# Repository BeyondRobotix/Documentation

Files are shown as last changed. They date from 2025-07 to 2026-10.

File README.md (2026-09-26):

# Beyond Robotix Documentation

Documentation for [Beyond Robotix](https://www.beyondrobotix.com/) hardware and firmware.

## Heated Pitot

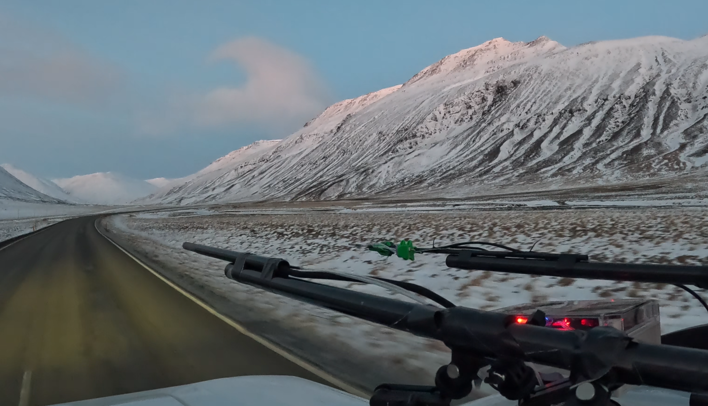
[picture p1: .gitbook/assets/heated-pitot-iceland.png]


Keeps aircraft airspeed readings accurate through extreme icing and wet conditions, with DroneCAN control and precise heater power management.

* [Heated Pitot](heated-pitot/)

## Kahuna

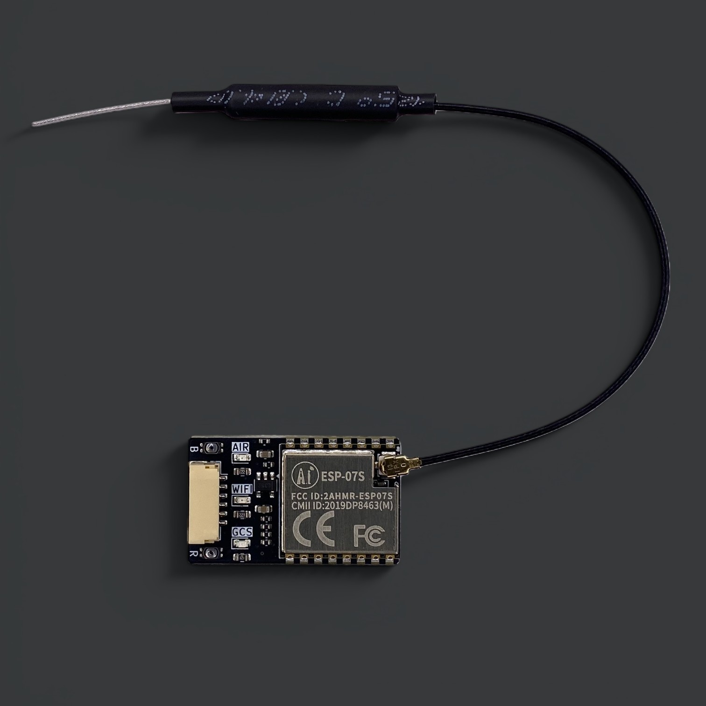
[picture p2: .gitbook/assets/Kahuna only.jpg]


A Wi-Fi telemetry unit for the Pixhawk ecosystem. Connect from any laptop or tablet with Mission Planner or QGroundControl, with multi-drone support and long range up to 2.5km.

* [Kahuna](kahuna/)
* [Quick Start Guide](kahuna/quick-start-guide.md)

## CAN Ecosystem

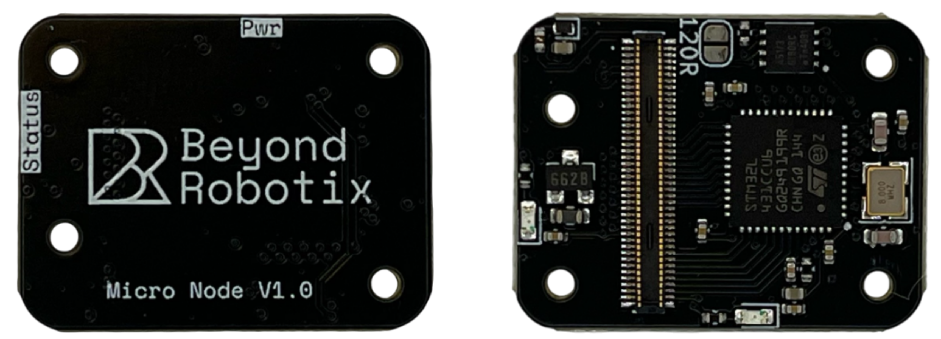
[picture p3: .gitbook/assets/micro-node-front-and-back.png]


Hardware and firmware for building custom DroneCAN peripherals, from ready-made nodes to Arduino-based custom firmware.

* [CAN Ecosystem overview](can-ecosystem/)
* [Micro Node](can-ecosystem/micro-node.md) — a compact CAN node that mounts to a custom carrier board
* [Node Development Board V1.1](can-ecosystem/node-development-board-v1.1.md) — breaks out every Micro Node interface for development
* [CAN Node](can-ecosystem/l431-can-node.md) — the same STM32L431 as the Micro Node, in a standalone form factor
* [CAN Node Plus](can-ecosystem/can-node-plus.md) — dual CAN FD interfaces and an STM32H723 for more demanding applications
* [Arduino DroneCAN](can-ecosystem/arduino-dronecan/) — build custom firmware for any of our nodes with a familiar Arduino sketch
* [AP Periph](can-ecosystem/ap-periph.md) — the ready-made ArduPilot peripheral firmware our nodes ship with by default

## Air Data Module

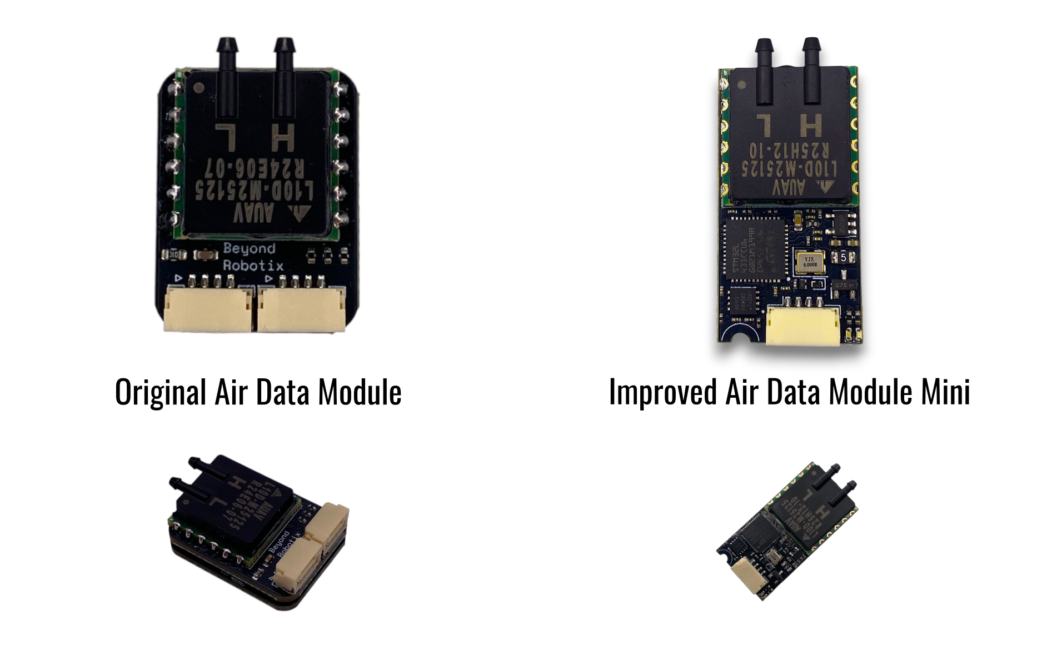
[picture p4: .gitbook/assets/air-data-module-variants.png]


A DroneCAN airspeed and altitude sensor built around the AllSensors AUAV pressure sensor, supporting a range of autopilots.

* [Air Data Module](air-data-module/)
* [Quick Start Guide](air-data-module/quick-start-guide.md)
* [Air Data Module Mini](air-data-module/air-data-module-mini.md) — a more compact, reliable redesign of the original module
* [Air Data Module Original](air-data-module/air-data-moulde-original.md) — the original two-layer design, mounted on a Micro Node

## RM3100 DroneCAN Compass

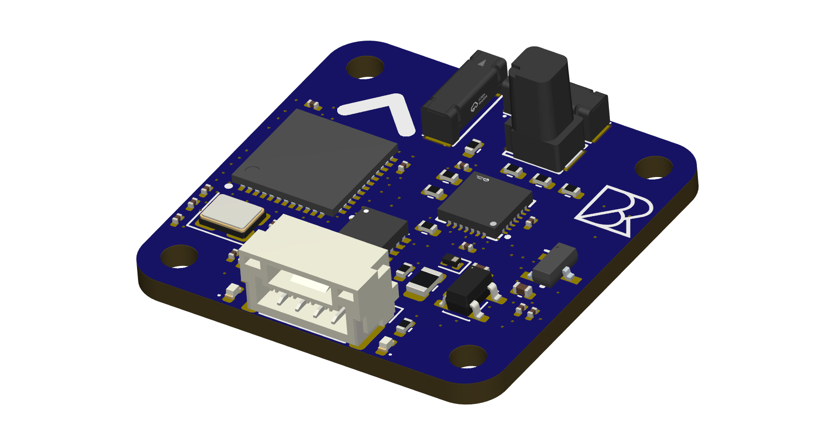
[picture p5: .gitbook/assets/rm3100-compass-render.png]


A plug-and-play DroneCAN magnetometer node built around the PNI RM3100 sensor, with the standard Pixhawk JST-GH connector.

* [RM3100 DroneCAN Compass](rm3100-dronecan-compass.md)

## Core Autopilot

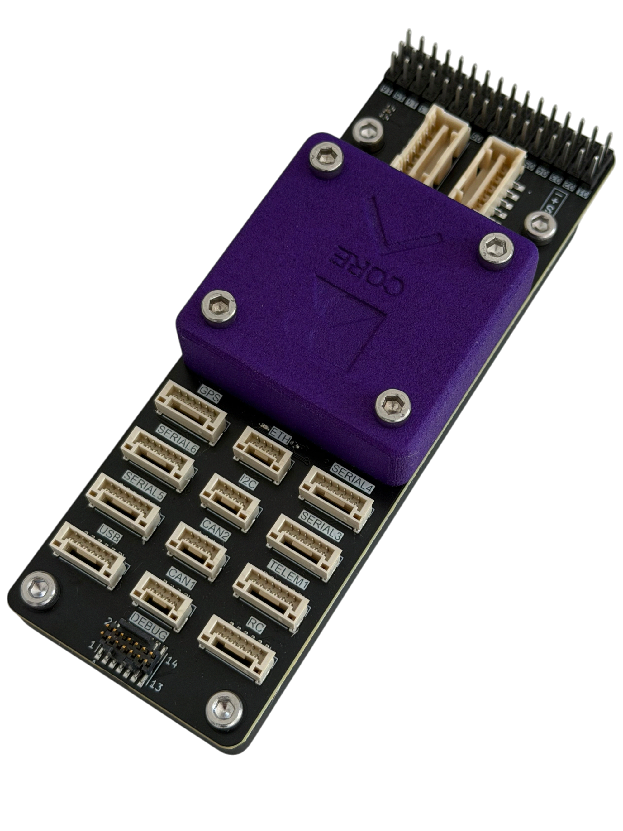
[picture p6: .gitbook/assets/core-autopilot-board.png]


An ArduPilot and PX4 compatible autopilot with 16 PWMs, Ethernet, 7 serials, 2 CAN and I2C, built around a modular Core plus carrier board design.

* [Core Autopilot](core-autopilot/)
* [Core Pinout](core-autopilot/core-pinout.md) — integrate the Core into your own carrier board
* [Default Carrier](core-autopilot/default-carrier-pinout.md) — pinout and mechanical for our reference carrier
* [Core Power](core-autopilot/core-power.md)

## Reference

* [Engineering Change Notice](engineering-change-notice.md) — hardware changes to our products (see GitHub releases for software changes)

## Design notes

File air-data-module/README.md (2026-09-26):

---
description: DroneCAN enabled AUAV absolute and differential pressure sensor
---

# Air Data Module

## Introduction

The Beyond Robotix Air Data Modules makes use of the Allsensors AUAV sensor. This module has a differential and absolute pressure sensors to estimate airspeed and altitude. The module works over DroneCAN with a variety of autopilots.

<figure><figcaption></figcaption></figure>

There are 5 variants of the air data module, each with their own maximum speeds:

* L05D → 45m/s&#x20;
* L10D → 63m/s
* L30D → 111m/s
* L60D → 149m/s
* L100D → 193m/s

For the best performance, choose the variant with the lowest speed that your platform will not exceed the maximum speed of. For example, if your platforms maximum speed is 50m/s, choose the L10D with the upper limit of 63 m/s. The L05D is not suitable as you will saturate the sensor. Going marginally over the maximum speed of the sensor will not damage it. The proof pressure (the point where the sensor will exhibit permenant damage) is 67 kPa, which equates to about 330 m/s - approximately Mach 0.97!

### Buy Now

{% embed url="https://www.beyondrobotix.com/products/air-data-module" %}

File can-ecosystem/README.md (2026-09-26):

# CAN Node System

The micro CAN node system allows easy integration of a CAN node into your project! We've solved the CAN node hardware and software problems, so you can create your custom solution rapidly.

If you're interested in a custom carrier board, or have any engineering enquiries please contact us at admin@beyondrobotics.com. We can also write custom firmwares for you!

## Getting Started

If you've just received your CAN node product, we have all the hardware and software details here!

If you can't find something in the docs or have more questions, contact us at **admin@beyondrobotix.com**

### Micro Node

The Micro Node carriers the STM32L431 chip with all required hardware. It has a high density connector to interface with the Node Develpment board, or any other board that fits a Micro Node.

{% embed url="https://www.beyondrobotix.com/products/micro-can-node" %}

<figure><figcaption><p>Micro Node </p></figcaption></figure>

### Node Development Board

The Node Development Board breaks out all the interfaces from the mounted node, including UART, SPI, I2C, USB, STLINK, CAN, Analogue and GPIOs.

{% embed url="https://www.beyondrobotix.com/products/micro-can-node-development-bundle" %}

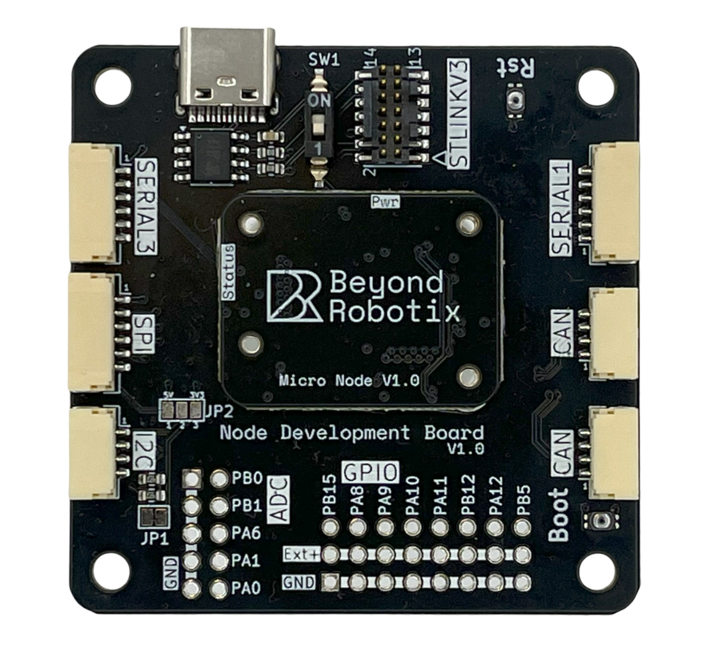
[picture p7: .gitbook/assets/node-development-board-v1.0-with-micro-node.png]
<figure><figcaption><p>Carrier board with Micro Node Mounted</p></figcaption></figure>

### CAN Node

The same STM32L431 as the Micro Node, but as a standalone board rather than one that mounts to a carrier. Interfaces come out on JST-GH connectors and a 2.54mm header, and it has the same debug port for developing Arduino DroneCAN applications. Pick this one when you don't need a custom carrier board.

{% embed url="https://www.beyondrobotix.com/products/can-node" %}

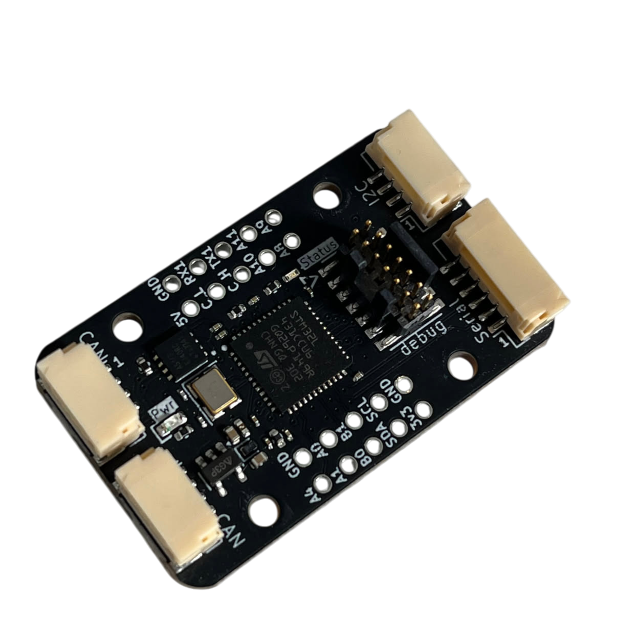
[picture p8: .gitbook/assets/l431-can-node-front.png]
<figure><figcaption><p>CAN Node</p></figcaption></figure>

{% content-ref url="l431-can-node.md" %}
[l431-can-node.md](l431-can-node.md)
{% endcontent-ref %}

### CAN Node Plus

Our H7 node. Two fully independent CAN FD interfaces, a lot more processing power than the L431 nodes, and JST-GH connectors for serial, I2C, SPI and PWM following the same conventions as an autopilot.

{% embed url="https://www.beyondrobotix.com/products/can-node-plus" %}

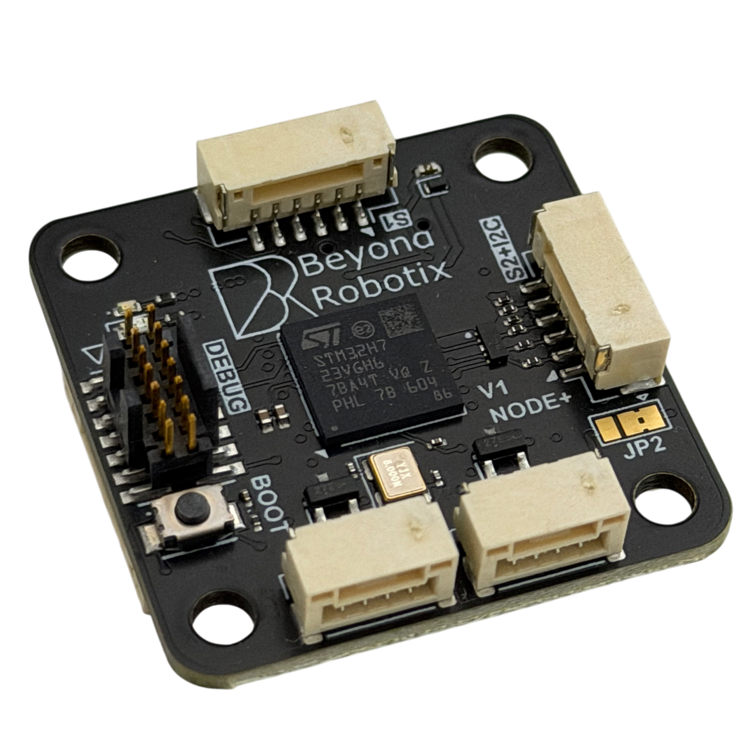
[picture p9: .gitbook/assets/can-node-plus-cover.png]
<figure><figcaption><p>CAN Node Plus</p></figcaption></figure>

{% content-ref url="can-node-plus.md" %}
[can-node-plus.md](can-node-plus.md)
{% endcontent-ref %}

### Arduino DroneCAN

You can integrate your sensor how you like with minimal code and using pre-existing Arduino libraries. Includes bootloader support so your apps can be updated over CAN.

Perfect for your custom hardware solutions, or if you want to implement your own logic!

{% content-ref url="arduino-dronecan/" %}
[arduino-dronecan](arduino-dronecan/)
{% endcontent-ref %}

### AP Periph

Ardupilots swiss army knife, no code required with many common sensors supported [https://ardupilot.org/dev/docs/ap-peripheral-landing-page.html](https://ardupilot.org/dev/docs/ap-peripheral-landing-page.html)

Details on our specific AP periph firmware are on the following page:

{% content-ref url="ap-periph.md" %}
[ap-periph.md](ap-periph.md)
{% endcontent-ref %}

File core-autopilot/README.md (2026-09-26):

# Core Autopilot

{% hint style="info" %}
This page is under construction. Please contact admin@beyondrobotix.com for further information.
{% endhint %}

<figure style="text-align: center"><figcaption><p>Beyond Robotix Core Autopilot </p></figcaption></figure>

The Beyond Robotix Core is an Ardupilot and PX4 compatible autopilot, aimed to increase the flexibility and number of interfaces over other solutions whilst being simple to integrate into any drone. 16 PWMs, Ethernet, 7 serials, 2 CAN and I2C all contribute to ensure you can achieve what you need to.

The Core integrates all power conditioning and switching within the core, so a carrier board only needs to route from the high density connectors to the carrier outputs.

## Sensors

The core contains tripple redundant IMUs, dual barometers and a single Magnetometer. All sensors are heated using a 2W heater to ensure they operate consistently in any scenario. The 2W heater is able to bring the sensors to working temperature within minutes even at extreme cold temperatures. 

| Sensor | Part |
| --- | --- |
| IMU | 2× IIM-42652, 1× BMI088 |
| Barometer | 2× MS5611 |
| Magnetometer | 1× BMM350 |

## Power

The Core accepts power through 4 interfaces
- USB C
- USB JST-GH header
- Power 1
- Power 2

The following applies to the inputs:
- All inputs and all outgoing 5 V rails are clamped at 5.5 V against transients
- Every input is filtered and reverse-blocked
- The highest voltage input is used, or, similar voltage sources are shared.
- The power inputs expect a 4.8V-5.75V input, with a recommended input of 5.3V.

### Power outputs
The core has 3 power lanes. One directly for the processor which is the priority, then 2 avionics lanes, Telem and peripherals. 

<figure><figcaption><p>5V bus distribution on the power layer</p></figcaption></figure>

### Redundancy behaviour

Each input is independently protected and reverse-blocked. A source that fails, is disconnected, or drops outside the accepted voltage window is isolated automatically, without disturbing the others and without back-feeding the board or another source. Changeover requires no configuration, and the board continues on whatever remains.

## Connectivity

- 2x CAN interfaces
- Ethernet
- USB
- microSD
- SWD/JTAG debug
- 7 Serial
- I2C

{% hint style="info" %}
USB signals are common between the USB-C connector on the side of the core and the USB connector on the connector layer.
{% endhint %}

- All digital signal lines have ESD protection 
- Analogue inputs are series-protected and filtered

## Mechanical

The core and its carrier boards are designed to be removable from an aircraft after being mounted, all screws are top accessible which allows maintenance once the aircraft has been built. The core and carriers use M3 screws to keep tooling consistent.

Carrier board mechanical (outline, mounting holes, STEP file) is covered on the [Default Carrier](default-carrier-pinout.md#mechanical) page.

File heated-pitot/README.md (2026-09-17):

# Heated Pitot

{% hint style="info" %}
This page is under construction. Please contact admin@beyondrobotix.com for further information.
{% endhint %}

The Beyond Robotix Heated Pitot allows aircraft to continue reading airspeed during extreme icing and wet conditions. It's able to operate at high airspeeds, with significant heating power on demand if required. The probe integrates our AUAV airspeed sensor module, for altitude and airspeed estimates over wide speed range options. DroneCAN is used for readings and optional control, with support for both Ardupilot and PX4. Our electronics allow precise power control, meaning your avionics system is not put under stress even when high heating power is required.

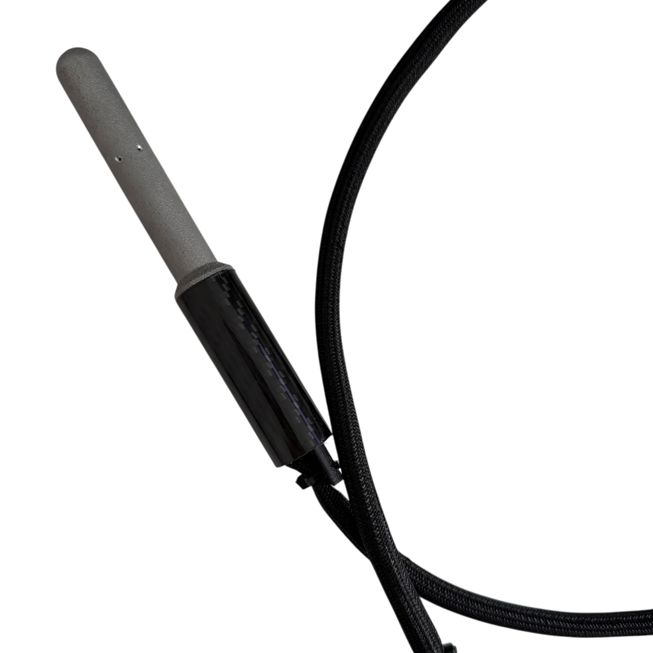
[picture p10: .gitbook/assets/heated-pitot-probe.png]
<div><figure><figcaption></figcaption></figure> <figure><figcaption></figcaption></figure></div>

For large volume orders, we can support custom options:
- loom length between control module and pitot
- Tube length to the probe
- Custom mounts

## Mechanical

### Probe 

{% file src="../.gitbook/assets/Beyond Robotix Heated Pitot Space Model.step" %}

### Control module

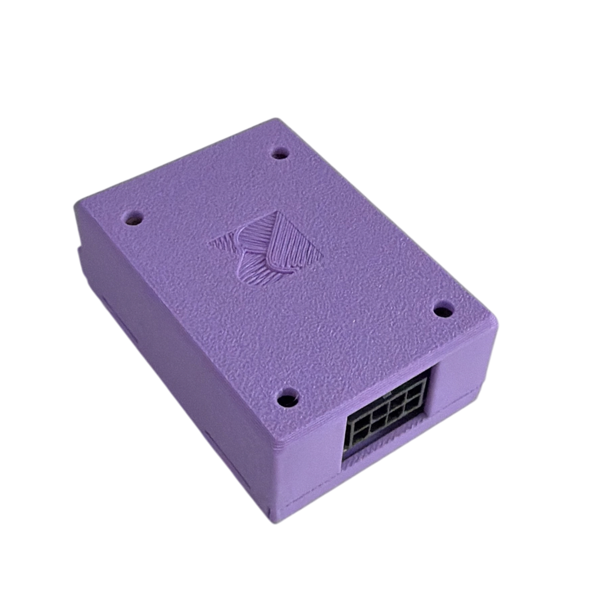
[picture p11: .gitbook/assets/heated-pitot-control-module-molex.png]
<figure><figcaption></figcaption></figure>

{% file src="../.gitbook/assets/Heated Pitot Control Module.step" %}

## Electrical

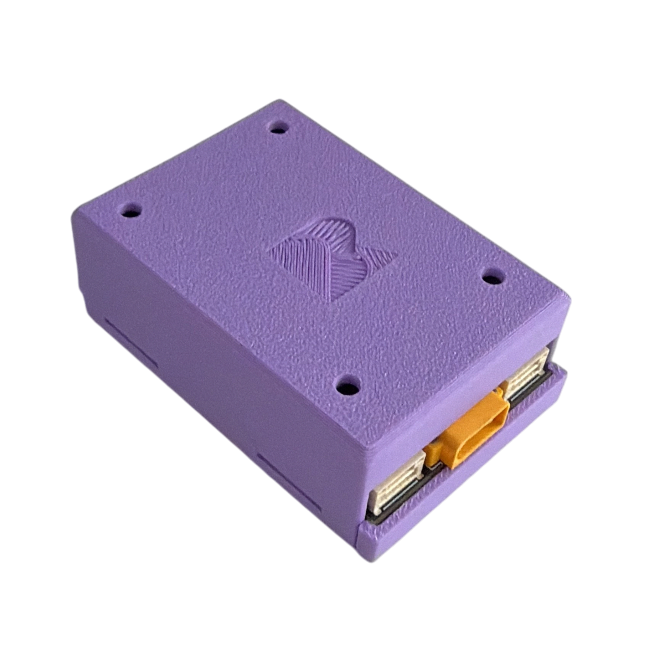
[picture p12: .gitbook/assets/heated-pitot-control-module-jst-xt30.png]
<figure><figcaption></figcaption></figure>

{% hint style="warning" %}
Below 12V, the maximum available heater power output will reduce. The pitot may operate down to 9V. Below 12V operation is not recommended.
{% endhint %}

| Parameter | Value |
| --- | --- |
| Input Voltage Range | 12 - 53 V |
| Maximum Power Consumption | 70 W (settable, see `P_MAX`) |
| Standby Power | 1 W |
| Operating Temperature Range | -40 °C to +80 °C |
| Power Connector | XT30 |
| 5V / CAN Connector | 2x standard 4 pin JST-GH |

### Power Consumption

The pitot targets a set temperature and adjusts heater power output to meet temperature demand. We recommend a 60 degree target temperature to ensure ice is melted as quickly as possible. For this given target temperature, the power output varies depending on airspeed, atmospheric temperature, altitude, snow/water air content.

The following shows power consumption varying with airspeed and atmospheric temperature at sea level, assuming dry conditions. To factor in melting ice, an additional 5W to all figures should be added to compensate for this.

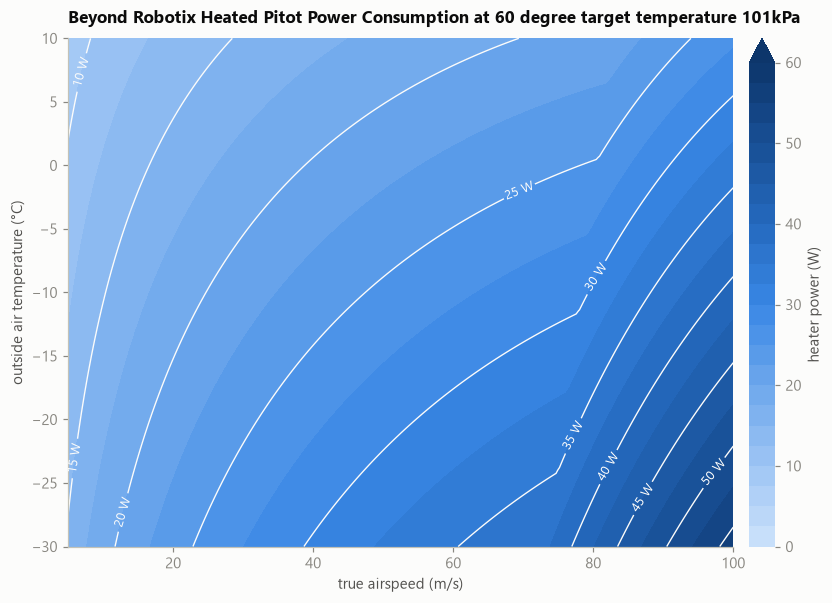
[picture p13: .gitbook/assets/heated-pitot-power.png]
<figure><figcaption></figcaption></figure>

Some advanced parameters can be set to reduce power consumption depending on your operating scenaio. See below and contact admin@beyondrobotix.com if you would like to discuss.

{% content-ref url="parameters.md" %}
[parameters.md](parameters.md)
{% endcontent-ref %}

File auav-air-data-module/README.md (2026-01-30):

---
description: DroneCAN enabled AUAV absolute and differential pressure sensor
---

# AUAV Air Data Module

## Introduction

The Beyond Robotix Air Data Module makes use of differential and absolute pressure sensors to estimate airspeed and altitude. The module works over DroneCAN with a variety of autopilots.

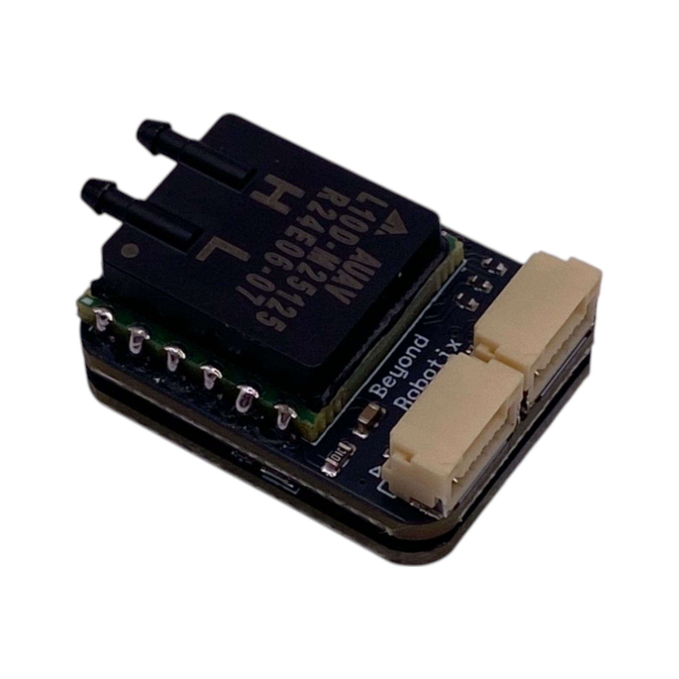
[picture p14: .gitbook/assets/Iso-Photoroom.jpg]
<figure><figcaption></figcaption></figure>

There are 5 variants of the air data module, each with their own maximum speeds:

* L05D -> 45m/s
* L10D -> 63m/s
* L30D -> 111m/s
* L60D -> 149m/s
* L100D -> 193m/s

It's best to choose the lowest speed variant which your platform will not exceed the maximum speed of.

It can be purchased here:

{% embed url="https://www.beyondrobotix.com/products/air-data-module" %}

## Pinout

<table><thead><tr><th width="316" align="right">Pin</th><th>Function</th><th data-hidden>Notes</th></tr></thead><tbody><tr><td align="right">1</td><td>5V</td><td>Recommended: 4.5 - 6V</td></tr><tr><td align="right">2</td><td>CAN H</td><td></td></tr><tr><td align="right">3</td><td>CAN L</td><td></td></tr><tr><td align="right">4</td><td>GND</td><td></td></tr></tbody></table>

{% hint style="info" %}
The CAN ports are common that can be used to daisy chain to other CAN nodes.
{% endhint %}

The computation on the Air Data Module is performed on the [CAN Node](../can-node-system/micro-node.md). If you would like to terminate the CAN bus at the Air Data Module, a solder jumper labeled `120R` can be jumped.

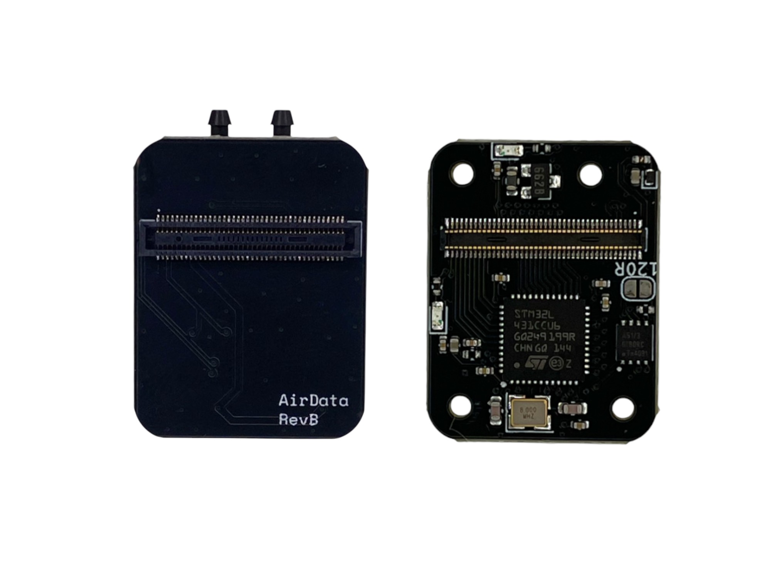
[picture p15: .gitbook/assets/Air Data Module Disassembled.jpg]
<figure><figcaption></figcaption></figure>

## Parameters

| Parameter | Description | Accepted Values |
| --- | --- | --- |
| NodeID | The ID the node will appear as in the CAN bus | 1-127 |
| Sensor\_Pressure | This is the type of AUAV sensor installed on the Air Data Module. | <p>L05D = 5<br>L10D = 10<br>L30D = 30<br>L60D = 60<br>L100D = 100</p> |

## Firmware

Our air data module runs on custom firmware which can be found here, including the latest firmware binaries:

{% embed url="https://github.com/BeyondRobotix/AUAV-DroneCAN/releases/latest" %}

To update to the latest firmware, there are two methods you can use:

* Mission Planner
* DroneCAN GUI&#x20;

### Updating: Mission Planner

1. Connect to your Flight Controller in Mission Planner
2. Go to Setup > Optional Hardware > UAVCAN
3. Click `CAN1` or `CAN2` (Depending on the bus you are connected to)
4. Click on `Menu` next to the Air Data Module
5. Click Update Firmware
6. Select the `.bin` file from the latest release page above

### Updating: DroneCAN GUI

1. Connect to your Flight Controller in DroneCAN GUI
2. Double Click on the Air Data Module
3. Click Update Firmware
4. Select the `.bin` file from the latest release page above

You are now on the latest version of the firmware!

## Mechanical

Images of hole spacing and overall dimensions are provided below. Additionally, the case STL files can&#x20;

### Case Specifications

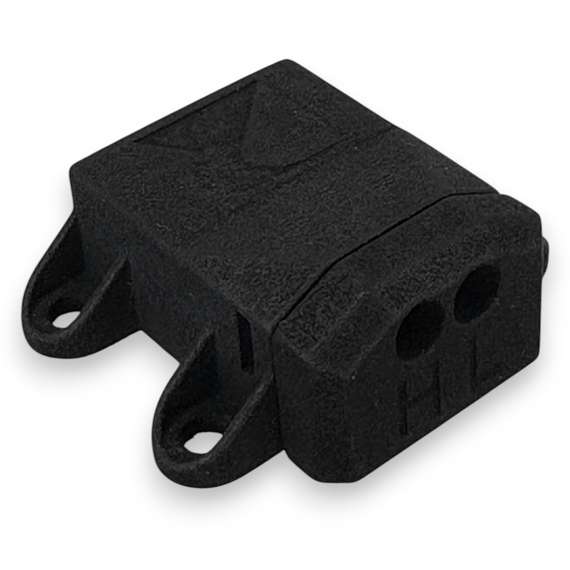
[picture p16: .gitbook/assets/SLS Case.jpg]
<figure><figcaption></figcaption></figure>

Specifcations for the size and shape of the case:

{% file src="../.gitbook/assets/Mechanical Drawing Air Data Module Case.pdf" %}

Files to 3D print/edit the included case:

{% file src="../.gitbook/assets/BR AUAV ADM Lid.3mf" %}

{% file src="../.gitbook/assets/BR AUAV ADM Base.3mf" %}

{% file src="../.gitbook/assets/BR AUAV ADM Lid.step" %}

{% file src="../.gitbook/assets/BR AUAV ADM Base.step" %}

### PCB Specifications

{% file src="../.gitbook/assets/Mechanical Drawing Air Data Module.pdf" %}

{% file src="../.gitbook/assets/AUAV DroneCAN Air Data Module.step" %}

Please note: this product is designed to require the case. Without it, the Micro CAN node will need mechanically stabilising through another means.

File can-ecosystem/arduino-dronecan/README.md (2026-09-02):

---
description: >-
  A library to send CAN messages compatible with Ardupilot and PX4 UAV
  autopilots.
icon: binary
---

# Arduino DroneCAN

## About

We made a library to make DroneCAN development as simple as possible. the Arduino DroneCAN repository allows you to get started with Ardupilot/PX4 compatible CAN messages and functionality straight out of the box using Beyond Robotix CAN node hardware.&#x20;

{% hint style="warning" %}
This documentation is written for the 2.X version of the library. If you're on a different version, the main.cpp file of your version should demonstrate the interface of that version. The 1.X interface is different in a few places - see [Upgrading from 1.X](./#upgrading-from-1.x) at the bottom of this page.
{% endhint %}

Github Repository:

{% embed url="https://github.com/BeyondRobotix/Arduino-DroneCAN" %}

## Supported hardware

The same application code builds for all of our CAN nodes. Which board you pick in PlatformIO decides the pinmap, the linker script and which CAN driver gets compiled in.

<table><thead><tr><th width="170">Board</th><th width="110">MCU</th><th width="90">Flash</th><th width="90">CAN FD</th><th width="110">CAN ports</th><th>PlatformIO environment</th></tr></thead><tbody><tr><td>Micro Node</td><td>STM32L431</td><td>256 KB</td><td>No</td><td>1</td><td><code>Micro-Node-App</code></td></tr><tr><td>CAN Node</td><td>STM32L431</td><td>256 KB</td><td>No</td><td>1</td><td><code>Micro-Node-App</code></td></tr><tr><td>CAN Node Plus</td><td>STM32H723</td><td>1 MB</td><td>Yes</td><td>2</td><td><code>Micro-Node-Plus-App</code></td></tr><tr><td>Core Node</td><td>STM32H743</td><td>2 MB</td><td>Yes</td><td>2</td><td><code>Core-Node-App</code></td></tr></tbody></table>

The two ports on the H7 boards are fully independent interfaces, not a shared bus brought out twice. Each one is its own DroneCAN node with its own node ID and its own parameter values, so a single board can sit on two separate CAN buses at once - or bridge them, if that's what you want. See [Two CAN ports](#two-can-ports).

The CAN Node is the same L431 as the Micro Node in a standalone form factor, so the two share an environment. For each board's connectors, pinouts and interfaces, see its own page in this section.

## Installation

There are a few ways of working with Arduino Code, we recommend the following steps for seamless integration with the project.

1. Install Visual Studio Code [https://code.visualstudio.com/download](https://code.visualstudio.com/download)
2. Install the PlatformIO extension [https://platformio.org/install/ide?install=vscode](https://platformio.org/install/ide?install=vscode)
3. Download the project [https://github.com/BeyondRobotix/Arduino-DroneCAN/releases](https://github.com/BeyondRobotix/Arduino-DroneCAN/releases)
4. Select the environment for your board from the PlatformIO status bar
5. Connect your STLINK to your CAN node
6. Press upload!

There are no submodules any more, so a plain clone is all you need:

```
git clone https://github.com/BeyondRobotix/Arduino-DroneCAN.git
```

The library and the board definitions live in their own repositories and are fetched by PlatformIO on the first build, pinned to a version in `platformio.ini`:

```ini
[env]
platform = https://github.com/BeyondRobotix/br_platformio_hwdef.git#v1.1
lib_deps = https://github.com/BeyondRobotix/libArduinoDroneCAN.git#v2.0.0
```

The first build takes a couple of minutes while these download. To move to a newer library, change the `#vX.Y.Z` tag and delete `.pio/libdeps/` so PlatformIO re-fetches it. To pick up a new platform release, run `pio pkg uninstall --platform br-stm32 -g`.

## Bootloader details

ArduinoDroneCAN uses our own bootloader, [BR\_bootloader](https://github.com/BeyondRobotix/BR_bootloader), to allow app updates over CAN. The standard AP\_Bootloader cannot be used.

You don't need to flash it separately. The bootloader binary for each board ships inside the `br_platformio_hwdef` platform, and any environment ending in `-App` flashes the bootloader and your app in one go on upload. A brand new board is fully provisioned by a single `pio run -t upload`.

## Breakpoint debugging

This works as standard in PlatformIO debugging! It previously needed a special flash without the bootloader, but this is no longer an issue.

## Detailed Example

The Arduino DroneCAN project reduces using DroneCAN down to creating an object, initialising the object, and one method to call in your loop function.&#x20;

### General advice

* Avoid the delay() function! this will disrupt any CAN activities. We show best practises for your loop function later
* Respect the watchdog. IWatchdog.reload() needs calling within the timeout time (2 seconds in our examples)
* Following the format of our example [https://github.com/BeyondRobotix/Arduino-DroneCAN/blob/master/src/main.cpp](https://github.com/BeyondRobotix/Arduino-DroneCAN/blob/master/src/main.cpp) will reduce the likelyhood of strange behaviour.
* If your program starts acting up, strip your program back to our example and build gradually from there. You'll find where bugs get introduced.
* If your node goes into "maintenance" mode then it means your program is crashing

### The Setup

app\_setup, dronecan.init and IWatchdog.begin must all be called at the start of setup. Doing another activities before or between functions may result in instabilities. Remember, the watchdog is running after this so call IWatchdog.reload() if you do any long running activities.&#x20;

#### app\_setup()

```cpp
app_setup();
```

app\_setup is required to be called at the start of the Arduino setup() function. This function is required as part of the transfer from the bootloader to app control. The function is internally disabled when non bootloader mode is selected in PlatformIO.

#### dronecan.init()

If your node only needs to **send** messages, use the short form of init(). You just pass a parameter list and the name of the node for NodeInfo, and the library wires up the receive callbacks for you:

```cpp
dronecan.version_major = 1;
dronecan.version_minor = 0;
dronecan.init(
    custom_parameters,
    "Beyond Robotix Node"
);
```

If your node needs to **receive** messages, pass your own two callback functions as the first two arguments (we explain these later):

```cpp
dronecan.init(
    onTransferReceived, 
    shouldAcceptTransfer, 
    custom_parameters,
    "Beyond Robotix Node"
);
```

Both forms take the same optional arguments after the node name, all of which have sensible defaults:

<table><thead><tr><th width="180">Argument</th><th width="220">Default</th><th>What it does</th></tr></thead><tbody><tr><td><code>mode</code></td><td><code>CanMode::Classic</code></td><td>Classic CAN 2.0B, or CAN FD on H7 boards. See <a href="#can-fd">CAN FD</a></td></tr><tr><td><code>port</code></td><td><code>CanPort::PORT1</code></td><td>Which physical CAN port this instance uses. See <a href="#two-can-ports">Two CAN ports</a></td></tr><tr><td><code>storage_page</code></td><td><code>-1</code> (board default)</td><td>First flash page of the parameter storage region. Leave it alone unless you know you need to move it</td></tr><tr><td><code>persist_on_set</code></td><td><code>true</code></td><td>Whether a parameter written over CAN saves itself. See <a href="#parameters">parameters</a></td></tr></tbody></table>

#### Watchdog

```cpp
IWatchdog.begin(2000000);
```

Our program requires starting the watchdog, remove it at your own peril! (it's started in the bootloader and from our testing, starting it here again is best)&#x20;

### DroneCAN looping

The normal Arduino `loop()` function works. Older versions of this library needed all of your looping code inside a `while(true)` at the end of `setup()` - that restriction is gone. Sketches written the old way still run fine, so you don't have to rewrite them.

```cpp
void loop()
{
    // your code here

    dronecan.cycle();
    IWatchdog.reload();
}
```

#### Fixed interval loops

The following code sets us up to run our if statement at 10Hz, checking if 100ms has passed since our last call. This is because we want to only send our CAN message at 10Hz and we want to call our "dronecan.cycle()" function to be called as much as possible to ensure CAN messages are send and received in a timely manner. We want to avoid delay() as much as possible!

```cpp
const uint32_t now = millis();

    // send our battery message at 10Hz
    if (now - looptime > 100)
    {
        looptime = now;
```

#### Sensor reading

Next, we want to read in our sensor value. This could be from anything, a current monitor, position sensor.. in this example, we read in the temperature of our STM32 processor. You would have had to have initialised your sensor in setup() of course.

```cpp
int32_t vref = __LL_ADC_CALC_VREFANALOG_VOLTAGE(analogRead(AVREF), LL_ADC_RESOLUTION_12B);
int32_t cpu_temp = __LL_ADC_CALC_TEMPERATURE(vref, analogRead(ATEMP), LL_ADC_RESOLUTION_12B);
```

#### Sending DroneCAN messages

Next, we initialise our DroneCAN battery message packet and we assign one of its attributes a value from when we read in our sensor. We've used a battery message, since Ardupilot supports 8 of these by default, Mission planner can display information from any of these 8 and Ardupilot logs all battery instances. There may be messages suitable for your application, but be aware, Ardupilot does not support many DroneCAN messages.

```cpp
uavcan_equipment_power_BatteryInfo pkt {};
pkt.temperature = cpu_temp;
```

Finally,  we send our DroneCAN message. For some equipment type can messages, we can use this very simple function:

```cpp
sendUavcanMsg(dronecan, pkt);

// or, to set the transfer priority yourself
sendUavcanMsg(dronecan, pkt, CANARD_TRANSFER_PRIORITY_LOW);
```

{% hint style="info" %}
Pass the **dronecan object**, not `dronecan.canard`. The older `sendUavcanMsg(dronecan.canard, pkt)` form still compiles, but it doesn't know about the node's CAN FD setting, so on an FD node it will send that message as a classic CAN frame. See [CAN FD](#can-fd).
{% endhint %}

For messages which are not in this type list:

```python
messages = [
    "dronecan.sensors.hygrometer.Hygrometer",
    "dronecan.sensors.magnetometer.MagneticFieldStrengthHiRes",
    "dronecan.sensors.rc.RCInput",
    "dronecan.sensors.rpm.RPM",
    "uavcan.equipment.actuator.ArrayCommand",
    "uavcan.equipment.actuator.Status",
    "uavcan.equipment.ahrs.MagneticFieldStrength",
    "uavcan.equipment.ahrs.MagneticFieldStrength2",
    "uavcan.equipment.ahrs.RawIMU",
    "uavcan.equipment.ahrs.Solution",
    "uavcan.equipment.air_data.AngleOfAttack",
    "uavcan.equipment.air_data.IndicatedAirspeed",
    "uavcan.equipment.air_data.RawAirData",
    "uavcan.equipment.air_data.Sideslip",
    "uavcan.equipment.air_data.StaticPressure",
    "uavcan.equipment.air_data.StaticTemperature",
    "uavcan.equipment.air_data.TrueAirspeed",
    "uavcan.equipment.camera_gimbal.AngularCommand",
    "uavcan.equipment.camera_gimbal.GEOPOICommand",
    "uavcan.equipment.camera_gimbal.Status",
    "uavcan.equipment.device.Temperature",
    "uavcan.equipment.esc.RawCommand",
    "uavcan.equipment.esc.RPMCommand",
    "uavcan.equipment.esc.Status",
    "uavcan.equipment.esc.StatusExtended",
    "uavcan.equipment.gnss.Auxiliary",
    "uavcan.equipment.gnss.Fix",
    "uavcan.equipment.gnss.Fix2",
    "uavcan.equipment.gnss.RTCMStream",
    "uavcan.equipment.hardpoint.Command",
    "uavcan.equipment.hardpoint.Status",
    "uavcan.equipment.ice.FuelTankStatus",
    "uavcan.equipment.ice.reciprocating.Status",
    "uavcan.equipment.indication.BeepCommand",
    "uavcan.equipment.indication.LightsCommand",
    "uavcan.equipment.power.BatteryInfo",
    "uavcan.equipment.power.CircuitStatus",
    "uavcan.equipment.power.PrimaryPowerSupplyStatus",
    "uavcan.equipment.range_sensor.Measurement",
    "uavcan.equipment.safety.ArmingStatus",
]
```

we have to do the full boilerplate for a UAVCAN/DroneCAN message:

```cpp
uint8_t buffer[UAVCAN_EQUIPMENT_POWER_BATTERYINFO_MAX_SIZE];
uint32_t len = uavcan_equipment_power_BatteryInfo_encode(&pkt, buffer
    CANARD_TAO_ENCODE_ARG(true)
);
static uint8_t transfer_id;
CanardTxTransfer transfer_object = {
    .transfer_type = CanardTransferTypeBroadcast,
    .data_type_signature = UAVCAN_EQUIPMENT_POWER_BATTERYINFO_SIGNATURE,
    .data_type_id = UAVCAN_EQUIPMENT_POWER_BATTERYINFO_ID,
    .inout_transfer_id = &transfer_id,
    .priority = CANARD_TRANSFER_PRIORITY_LOW,
    .payload = buffer,
    .payload_len = (uint16_t)len,
};
canardBroadcastObj(&dronecan.canard, &transfer_object);
```

`transfer_id` has to be `static` (or global) - libcanard advances it for you after each successful send, so it needs to survive between calls.

{% hint style="info" %}
Older versions of this documentation showed the `canardBroadcast()` call with a long argument list. That function still exists, but its signature grows extra arguments on CAN FD builds, so it won't compile for the H7 boards. The `canardBroadcastObj()` form above builds everywhere. `CANARD_TAO_ENCODE_ARG()` is a helper macro from the library that expands to nothing on builds where the encoder doesn't take a tail-array-optimisation argument.
{% endhint %}

#### End of the loop

```cpp
dronecan.cycle();
IWatchdog.reload();
```

Outside our fixed interval if statment, we call our dronecan.cycle() method, which is required, and we also reset our watchdog timer. &#x20;

### Reading in CAN packets

onTransferReceived and shouldAcceptTransfer are defined in our program and passed to dronecan.init. These functions are used to recieve any DroneCAN messages. If your node only sends messages you can leave them out entirely and use the short form of init() - the library then handles the standard DroneCAN traffic on its own. We've put an example of decoding a Magnetometer message below. in onTransferRecieved, you can manipulate the recieved packet and use gobal variables or parameters etc to transfer information out of this function. DroneCANonTransferReceived must always be called at the end of this function for our library to work.

to allow a different message to be recieved, shouldAcceptTransfer needs the new message adding to it, following the same pattern as the magnetometer message example. As before, the last line of this function must remain the same for our library to work correctly.&#x20;

```cpp
/*
This function is called when we receive a CAN message, and it's accepted by the shouldAcceptTransfer function.
We need to do boiler plate code in here to handle parameter updates and so on, but you can also write code to interact with sent messages here.
*/
static void onTransferReceived(CanardInstance *ins, CanardRxTransfer *transfer)
{

    // switch on data type ID to pass to the right handler function
    // if (transfer->transfer_type == CanardTransferTypeRequest)
    // check if we want to handle a specific service request
    switch (transfer->data_type_id)
    {

    case UAVCAN_EQUIPMENT_AHRS_MAGNETICFIELDSTRENGTH_ID:
    {
        uavcan_equipment_ahrs_MagneticFieldStrength pkt{};
        uavcan_equipment_ahrs_MagneticFieldStrength_decode(transfer, &pkt);
        break;
    }
    }

    DroneCANonTransferReceived(dronecan, ins, transfer);
}

/*
For this function, we need to make sure any messages we want to receive follow the following format with
UAVCAN_EQUIPMENT_AHRS_MAGNETICFIELDSTRENGTH_ID as an example
 */
static bool shouldAcceptTransfer(const CanardInstance *ins,
                                 uint64_t *out_data_type_signature,
                                 uint16_t data_type_id,
                                 CanardTransferType transfer_type,
                                 uint8_t source_node_id)

{
    if (transfer_type == CanardTransferTypeBroadcast)
    {
        // Check if we want to handle a specific broadcast packet
        switch (data_type_id)
        {
        case UAVCAN_EQUIPMENT_AHRS_MAGNETICFIELDSTRENGTH_ID:
        {
            *out_data_type_signature = UAVCAN_EQUIPMENT_AHRS_MAGNETICFIELDSTRENGTH_SIGNATURE;
            return true;
        }
        }
    }

    return false || DroneCANshouldAcceptTransfer(ins, out_data_type_signature, data_type_id, transfer_type, source_node_id);
}
```

### Other things

#### parameters

```cpp
std::vector<DroneCAN::parameter> custom_parameters = {
    { "NODEID", DroneCAN::INT,  100,  1,    127 },
    { "PARM_1", DroneCAN::REAL, 0.0f, 0.0f, 100.0f },
    { "PARM_2", DroneCAN::REAL, 0.0f, 0.0f, 100.0f },
    { "PARM_3", DroneCAN::REAL, 0.0f, 0.0f, 100.0f },
};
```

We passed the custom\_parameters object into dronecan.init. This parameters object needs "NODEID" in the list since we use that. The first value after the type dictates the default value, second the minimum for the parameter and the last the maximum. These min/maxes may or may not be shown in Mission planner etc and may or may not make any functional difference.

`DroneCAN::INT`, `DroneCAN::REAL` and `DroneCAN::BOOL` are short aliases for the `UAVCAN_PROTOCOL_PARAM_VALUE_*` constants. The long names still work if you prefer them.

```cpp
dronecan.setParameter("PARM_1", 69);
Serial.print("PARM_1 value: ");
Serial.println(dronecan.getParameter("PARM_1"));
```

You can set and retrieve parameters easily. parameters get saved to flash so they'll be recalled on next boot.&#x20;

#### CAN FD

{% hint style="info" %}
CANFD support is experimental. So far bench tests have shown 2mpbs functioning, and some success with 4mpbs.
{% endhint %}

The H7 boards (MicroNode+ and Core Node) support CAN FD. Pass a `CanMode` to init() to turn it on:

```cpp
dronecan.init(custom_parameters, "Beyond Robotix Node", DroneCAN::CanMode::FD4X);
```

The arbitration bitrate is always 1 Mbps. The mode picks the data-phase multiplier on top of that, so match it to the autopilot's `CAN_Px_FDBITRATE` parameter:

<table><thead><tr><th width="220">CanMode</th><th width="180">Data phase bitrate</th><th>ArduPilot CAN_Px_FDBITRATE</th></tr></thead><tbody><tr><td><code>CanMode::Classic</code> (default)</td><td>n/a - CAN 2.0B</td><td>-</td></tr><tr><td><code>CanMode::FD2X</code></td><td>2 Mbps</td><td>2</td></tr><tr><td><code>CanMode::FD4X</code> (also <code>CanMode::FD</code>)</td><td>4 Mbps</td><td>4</td></tr><tr><td><code>CanMode::FD8X</code></td><td>8 Mbps</td><td>8</td></tr></tbody></table>

Once a node is initialised in an FD mode, `sendUavcanMsg(dronecan, pkt)` sends FD frames automatically. This is why you should pass the dronecan object rather than `dronecan.canard` - the `canard` form has no way to know the node is in FD mode and will send a classic frame instead.

The Micro Node's L431 has no FD hardware. Asking for an FD mode in a Micro Node build is a compile error rather than a runtime surprise.

#### Two CAN ports

The H7 boards have two CAN peripherals, and you can run both from one firmware by creating two `DroneCAN` objects. Each is an independent node with its own node ID, its own parameter values and its own transfer IDs:

```cpp
DroneCAN can1;
DroneCAN can2;

void setup()
{
    app_setup();
    IWatchdog.begin(2000000);

    can1.init(params_port1, "Beyond Robotix Node/Port1",
              DroneCAN::CanMode::FD, DroneCAN::CanPort::PORT1);
    can2.init(params_port2, "Beyond Robotix Node/Port2",
              DroneCAN::CanMode::FD, DroneCAN::CanPort::PORT2);
}

void loop()
{
    can1.cycle();
    can2.cycle();
    IWatchdog.reload();
}
```

Give the two instances different default NODEIDs so they don't collide on a shared bus. Both instances share the same pair of flash pages for parameter storage - each record is tagged with which instance it belongs to - so the second port costs no extra flash.

There is also `CanPort::BOTH`, which bridges the two ports into a single node: messages go out on both ports and received messages are merged. This is the redundant-interface setup ArduPilot expects when you wire one node to two buses.

The full working version of this is the `Dual_CAN` example. The Micro Node has a single CAN port and ignores the port argument.

### Full example!

This is `src/main.cpp` from the repository. It's a send-only node, so it uses the short form of init(). If you need to receive messages, add the two callback functions from [Reading in CAN packets](#reading-in-can-packets) and pass them as the first two arguments to init().

```cpp
#include <Arduino.h>
#include <dronecan.h>

// set up your parameters here with default values. NODEID should be kept
std::vector<DroneCAN::parameter> params_port1 = {
    {"NODEID", DroneCAN::INT,  100,  1,    127},
    {"PARM_1", DroneCAN::REAL, 0.0f, 0.0f, 100.0f},
    {"PARM_2", DroneCAN::REAL, 0.0f, 0.0f, 100.0f},
};

DroneCAN can1;

uint32_t looptime1 = 0;

void setup()
{
    app_setup();              // needed for coming from a bootloader, needs to be first in setup
    IWatchdog.begin(2000000); // if the loop takes longer than 2 seconds, reset the system
    Serial.begin(115200);

    can1.init(params_port1, "Beyond Robotix Node",
              DroneCAN::CanMode::Classic, DroneCAN::CanPort::PORT1);

    Serial.print("Port1 NODEID: "); Serial.println(can1.getParameter("NODEID"));
}

void loop()
{
    const uint32_t now = millis();

    // send our battery message at 10Hz
    // Don't use delay() since we need to call can1.cycle() as much as possible
    if (now - looptime1 > 100)
    {
        looptime1 = now;

        // collect MCU core temperature data
        int32_t vref     = __LL_ADC_CALC_VREFANALOG_VOLTAGE(analogRead(AVREF), LL_ADC_RESOLUTION_12B);
        int32_t cpu_temp = __LL_ADC_CALC_TEMPERATURE(vref, analogRead(ATEMP), LL_ADC_RESOLUTION_12B);

        // construct dronecan packet
        uavcan_equipment_power_BatteryInfo pkt{};
        pkt.voltage     = analogRead(PA1);
        pkt.current     = analogRead(PA0);
        pkt.temperature = cpu_temp;

        sendUavcanMsg(can1, pkt, CANARD_TRANSFER_PRIORITY_LOW);
    }

    can1.cycle();
    IWatchdog.reload();
}
```

`<dronecan.h>` pulls in everything the library needs, so the separate `<IWatchdog.h>`, `<app.h>`, `<vector>` and `<simple_dronecanmessages.h>` includes older examples carried are no longer required.

## Upgrading from 1.X

If you're moving an existing sketch from a 1.X release, these are the things that changed:

<table><thead><tr><th width="260">1.X</th><th>2.X</th></tr></thead><tbody><tr><td>Clone with <code>--recurse-submodules</code></td><td>No submodules. PlatformIO fetches the library and board definitions from <code>platformio.ini</code></td></tr><tr><td><code>Micro-Node-Bootloader</code> environment</td><td><code>Micro-Node-App</code>, plus <code>Core-Node-App</code> and <code>Micro-Node-Plus-App</code> for the H7 boards</td></tr><tr><td>Loop code inside <code>while(true)</code> in <code>setup()</code></td><td>Normal Arduino <code>loop()</code>. The old form still works</td></tr><tr><td>init() always needed the two callback functions</td><td>Callbacks are optional - omit them if your node only sends</td></tr><tr><td><code>sendUavcanMsg(dronecan.canard, pkt)</code></td><td><code>sendUavcanMsg(dronecan, pkt)</code>, so CAN FD is handled for you</td></tr><tr><td><code>DroneCANshoudlAcceptTransfer</code></td><td><code>DroneCANshouldAcceptTransfer</code> (spelling fixed)</td></tr><tr><td><code>UAVCAN_PROTOCOL_PARAM_VALUE_INTEGER_VALUE</code></td><td><code>DroneCAN::INT</code> and friends. The long names still work</td></tr><tr><td>Parameters needed "Store all" to persist</td><td>Parameters written over CAN save themselves</td></tr></tbody></table>

Reflashing a 1.X node with 2.X firmware resets its parameters to the defaults in your code, once. Note down anything you've changed from default before you upgrade.

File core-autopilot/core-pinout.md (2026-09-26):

# Core pinout
{% hint style="info" %}
This page is under construction. Please contact admin@beyondrobotix.com for further information.
{% endhint %}

This page is for integrating the core into your own carrier board. No licensing required! Since our core has all the power switching electronics in the core, producing a custom carrier becomes just routing the connector pins.

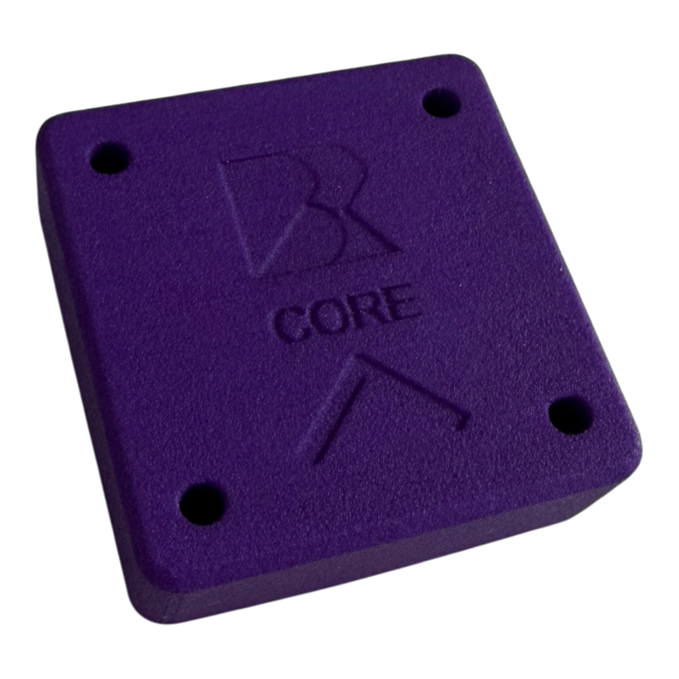
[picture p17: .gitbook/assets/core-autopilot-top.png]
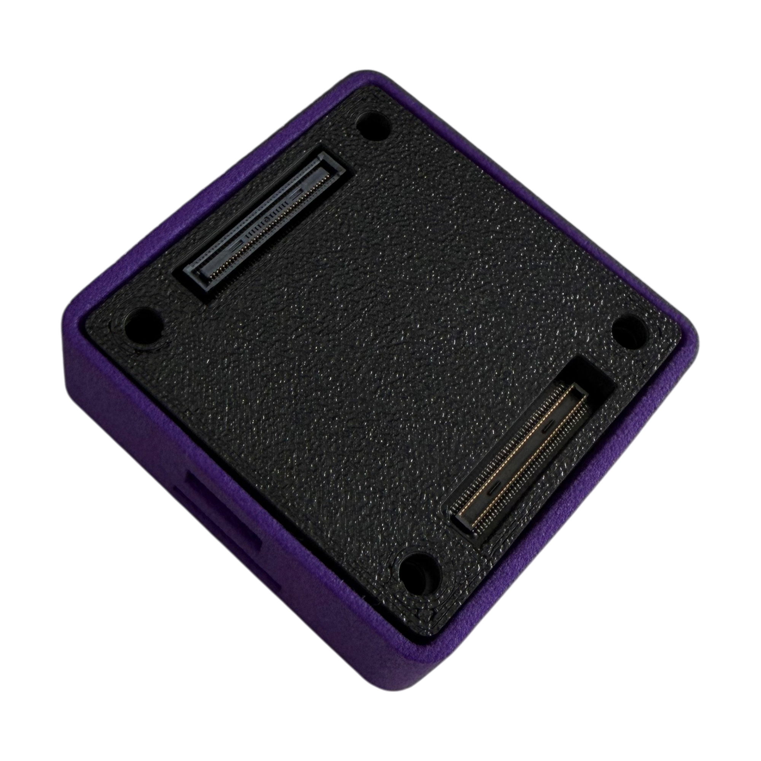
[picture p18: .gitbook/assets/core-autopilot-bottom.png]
<div><figure><figcaption><p>Top</p></figcaption></figure> <figure><figcaption><p>Bottom</p></figcaption></figure></div>

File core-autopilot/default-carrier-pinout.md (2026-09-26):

# Default Carrier

The default carrier is Beyond Robotix's reference connector layer for the Core, breaking out the high density connectors into standard peripheral connectors.

## Mechanical

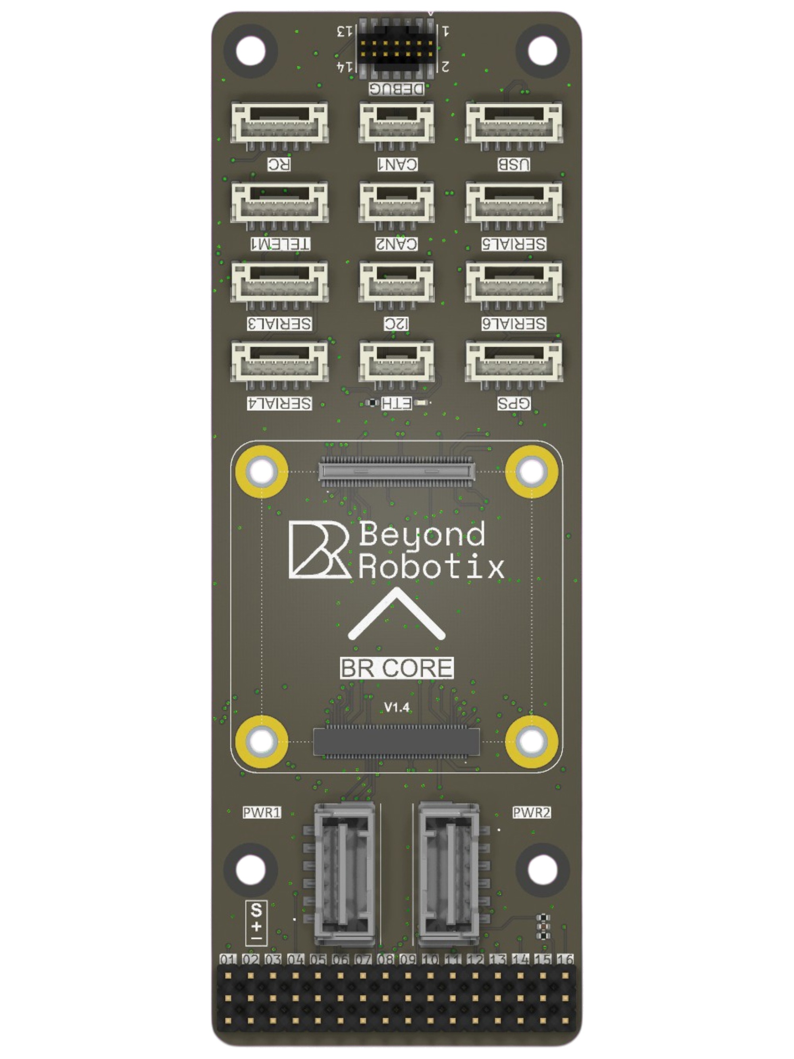
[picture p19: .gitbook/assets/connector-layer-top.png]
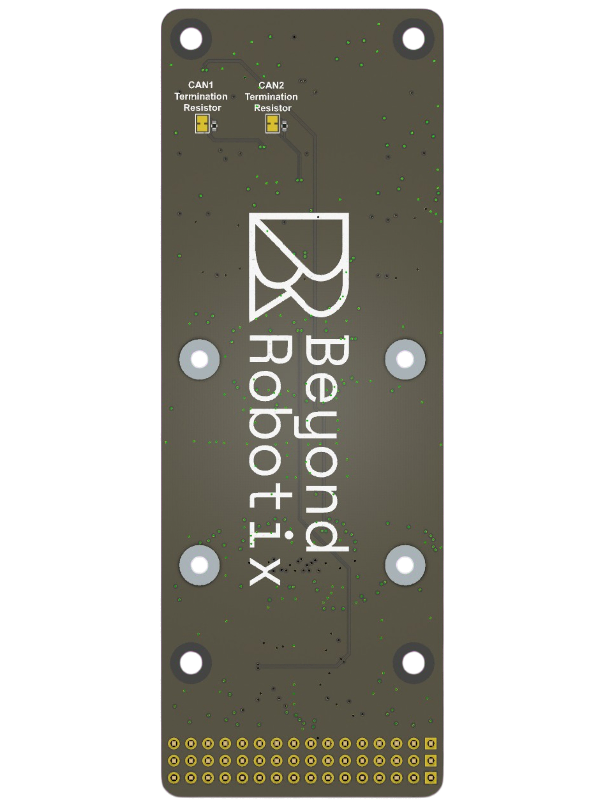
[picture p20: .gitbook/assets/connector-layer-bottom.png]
<div><figure><figcaption><p>Top</p></figcaption></figure> <figure><figcaption><p>Bottom</p></figcaption></figure></div>

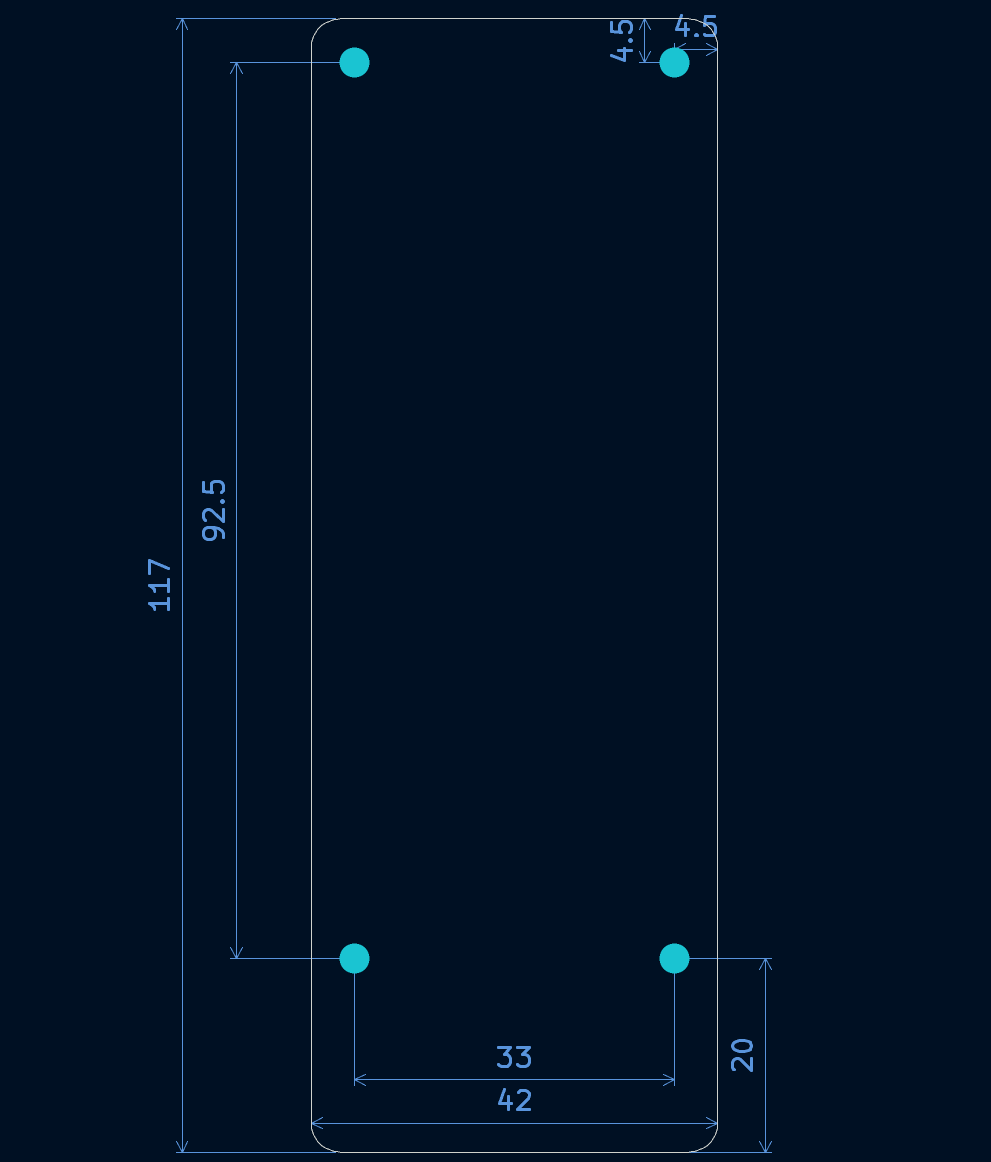
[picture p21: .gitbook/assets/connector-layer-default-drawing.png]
<figure><figcaption><p>Board outline and mounting hole dimensions (mm). All mounting holes are M3.</p></figcaption></figure>

{% file src="../.gitbook/assets/connector-layer-default.step" %}
CAD file for the carrier only
{% endfile %}

## Pinout

The carrier board pinouts follow Pixhawk standard pinouts!

### RC (Serial1)

6-pin, JST-GH 1.25 mm pitch.

Default protocol: RC input (SBUS/CRSF/etc.)\
ArduPilot parameter: `SERIAL1_PROTOCOL`

| Pin | Signal | Direction | Voltage |
| --- | --- | --- | --- |
| 1 | Peripherals 5V | Output | 5 V |
| 2 | TX | Output | 3.3 V |
| 3 | RX | Input | 3.3 V |
| 4 | NC | - | - |
| 5 | NC | - | - |
| 6 | GND | - | 0 V |

***

### TELEM1 (Serial2)

6-pin, JST-GH 1.25 mm pitch.

Default protocol: MAVLink 2\
ArduPilot parameter: `SERIAL2_PROTOCOL`\
Power rail: Telem 5 V (current-limited, see [Power](#power))

| Pin | Signal | Direction | Voltage |
| --- | --- | --- | --- |
| 1 | Telem 1 5V | Output | 5 V |
| 2 | TX | Output | 3.3 V |
| 3 | RX | Input | 3.3 V |
| 4 | CTS | Input | 3.3 V |
| 5 | RTS | Output | 3.3 V |
| 6 | GND | - | 0 V |

> This is the primary telemetry port. The 5 V rail on this connector is sourced from a dedicated current-limited supply separate from the general peripherals rail.

***

### SERIAL3

6-pin, JST-GH 1.25 mm pitch.

Default protocol: None (user-defined)\
ArduPilot parameter: `SERIAL3_PROTOCOL`

| Pin | Signal | Direction | Voltage |
| --- | --- | --- | --- |
| 1 | Peripherals 5V | Output | 5 V |
| 2 | TX | Output | 3.3 V |
| 3 | RX | Input | 3.3 V |
| 4 | CTS | Input | 3.3 V |
| 5 | RTS | Output | 3.3 V |
| 6 | GND | - | 0 V |

***

### SERIAL4 / SERIAL5 / SERIAL6

6-pin, JST-GH 1.25 mm pitch.

Default protocol: None (user-defined)

| Pin | Signal | Direction | Voltage |
| --- | --- | --- | --- |
| 1 | Peripherals 5V | Output | 5 V |
| 2 | TX | Output | 3.3 V |
| 3 | RX | Input | 3.3 V |
| 4 | NC | - | - |
| 5 | NC | - | - |
| 6 | GND | - | 0 V |

***

### GPS (Serial7)

6-pin, JST-GH 1.25 mm pitch.

Default protocol: GPS\
ArduPilot parameter: `SERIAL7_PROTOCOL`\
This port also carries I²C for an external compass.

| Pin | Signal | Direction | Voltage |
| --- | --- | --- | --- |
| 1 | Peripherals 5V | Output | 5 V |
| 2 | TX | Output | 3.3 V |
| 3 | RX | Input | 3.3 V |
| 4 | SCL | Output | 3.3 V |
| 5 | SDA | Output | 3.3 V |
| 6 | GND | - | 0 V |

> This is the recommended GPS port.

***

### CAN1 / CAN2

4-pin, JST-GH 1.25 mm pitch. Termination: 120 Ω installed on the connector layer.

| Pin | Signal | Direction | Voltage |
| --- | --- | --- | --- |
| 1 | Peripherals 5V | Output | 5 V |
| 2 | CAN_H | Bidir | - |
| 3 | CAN_L | Bidir | - |
| 4 | GND | - | 0 V |

> *n* is 1 or 2 depending on the connector. CAN1 maps to FDCAN1 (`CAN_P1_DRIVER = 1`), CAN2 maps to FDCAN2 (`CAN_P2_DRIVER = 1`).

***

### I²C

4-pin, JST-GH 1.25 mm pitch.

| Pin | Signal | Direction | Voltage |
| --- | --- | --- | --- |
| 1 | Peripherals 5V | Output | 5 V |
| 2 | SCL | Output | 3.3 V |
| 3 | SDA | Output | 3.3 V |
| 4 | GND | - | 0 V |

> I²C bus 2. Suitable for external compasses, barometers, or airspeed sensors that require I²C. The bus is buffered on the power layer.

***

### ETH (Ethernet)

4-pin, JST-GH 1.25 mm pitch.

| Pin | Signal | Direction | Voltage |
| --- | --- | --- | --- |
| 1 | TX\_P  | Output | - |
| 2 | TX\_N  | Output | - |
| 3 | RX\_P  | Input | - |
| 4 | RX\_N  | Input | - |

***

### USB

4-pin, JST-GH 1.25 mm pitch.

| Pin | Signal | Direction | Voltage |
| --- | --- | --- | --- |
| 1 | Pwr\_USB2\_In | Input | 5 V |
| 2 | USB\_P | Bidir | - |
| 3 | USB\_N | Bidir | - |
| 4 | GND | - | 0 V |

***

### DEBUG

14-pin, 1.27 mm pitch (FTSH-107-01-L-DV-K, compatible with standard ARM SWD cables).

| Pin | Signal |
| --- | --- |
| 1 | |
| 2 | |
| 3 | 3v3 |
| 4 | SWDIO  |
| 5 | GND |
| 6 | SWCLK  |
| 7 | GND |
| 8 | |
| 9 | |
| 10  | |
| 11  | GND |
| 12  | |
| 13  | RX8 |
| 14  | TX8 |

> UART8 is the ArduPilot debug console (`STDOUT_SERIAL SD8`, 57600 baud). Connect a 3.3 V FTDI cable to TX8/RX8 to view boot output and ArduPilot log messages.

***

### PWR1 / PWR2

6-pin, Molex CLIK-Mate 2.0 mm pitch power input connectors. PWR1 and PWR2 provide independent redundant power paths - either connector alone is sufficient to power the board.

| Pin | Signal  | Direction | Voltage |
| --- | --- | --- | --- |
| 1 | Pwr\_In | Input | 4.2–5.75 V |
| 2 | Pwr\_In | Input | 4.2–5.75 V |
| 3 | CAN2\_H | Bidir | - |
| 4 | CAN2\_L | Bidir | - |
| 5 | GND | - | 0 V |
| 6 | GND | - | 0 V |

> The power connectors CAN2 for our power input module with current/voltage monitoring

***

### PWM outputs

The 16 PWM outputs are available on a 3×16 row of 2.54 mm pitch through-holes at the bottom edge of the board, with three rows labelled **PWM**, **Spwr** (servo power), and **GND**.

| Row  | Function |
| ---- | --- |
| PWM  | Signal (level-shifted, 3.3 V or 5 V - see below) |
| Spwr | Servo rail power (**not a power output** - requires external regulator) |
| GND  | Ground |

PWM outputs 1–8 are the **MAIN** outputs and pass through the level shifter (voltage-selectable). PWM outputs 9–16 are **AUX** outputs and are direct 3.3 V GPIO.

| Output | ArduPilot function |
| --- | --- |
| PWM1 | MAIN 1 |
| PWM2 | MAIN 2 |
| PWM3 | MAIN 3 |
| PWM4 | MAIN 4 |
| PWM5 | MAIN 5 |
| PWM6 | MAIN 6 |
| PWM7 | MAIN 7 |
| PWM8 | MAIN 8 |
| PWM9 | AUX 1 |
| PWM10  | AUX 2 |
| PWM11  | AUX 3 |
| PWM12  | AUX 4 |
| PWM13  | AUX 5 |
| PWM14  | AUX 6 |
| PWM15  | AUX 7 |
| PWM16  | AUX 8 |

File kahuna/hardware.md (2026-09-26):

---
icon: microchip
---

# Hardware

## Pinouts

The connector to the autopilot is a 6-pin JST-GH connector. The pinouts on the Kahuna are inline with the pixhawk standard, hence an unmodified 6-pin JST-GH can be connected directly to any pixhawk standard autopilot. The TX and RX have been swapped appropriately on the Kahuna for a UART connection.

The antenna connector is a U.Fl connector (Also known as IPEX). You can connect an antenna directly to the board or use a U.Fl to SMA adaptor to connect to a wider range of antennas.

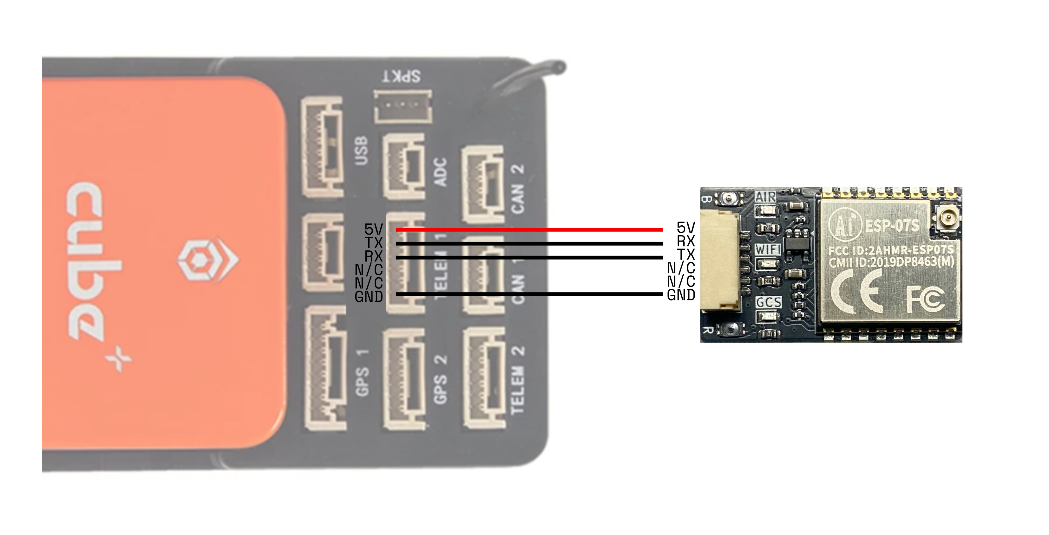
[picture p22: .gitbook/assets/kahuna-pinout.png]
<figure><figcaption><p>Kahuna Pinout</p></figcaption></figure>

## Buttons and Jumpers

Use the Kahuna's buttons and jumpers to enter bootloader mode or restore factory settings.

### Enter Bootloader Mode

To enter bootloader mode on the ESP07-S module, hold the **B** button and quickly tap the **R** button. If successful, the GCS Status LED will softly illuminate. Release the button when the LED lights up. For detailed steps on checking the module's health and firmware updates via UART, refer to the Firmware Update

### Factory Reset Jumper

The factory reset jumper lets you restore the Kahuna to its default settings, which is helpful if you've forgotten the username or password. To reset to factory defaults, short circuit the jumper on the underside of the board within one minute of powering on the Kahuna.

## LED Status Lights

The Kahuna device features three status indicators: Air, Wi-Fi, and GCS.

* **Air LED**: Indicates the status of communications between the Kahuna and the autopilot, specifically regarding the presence of a heartbeat.
* **Wi-Fi LED**: Shows the status of the Wi-Fi connection, for instance, whether the Kahuna is connected to a network or searching for one.
* **GCS LED**: Reflects the communication status between the Kahuna and the Ground Control Station software, again focusing on the presence of a heartbeat signal.

The table below outlines the meaning of the status light indications.

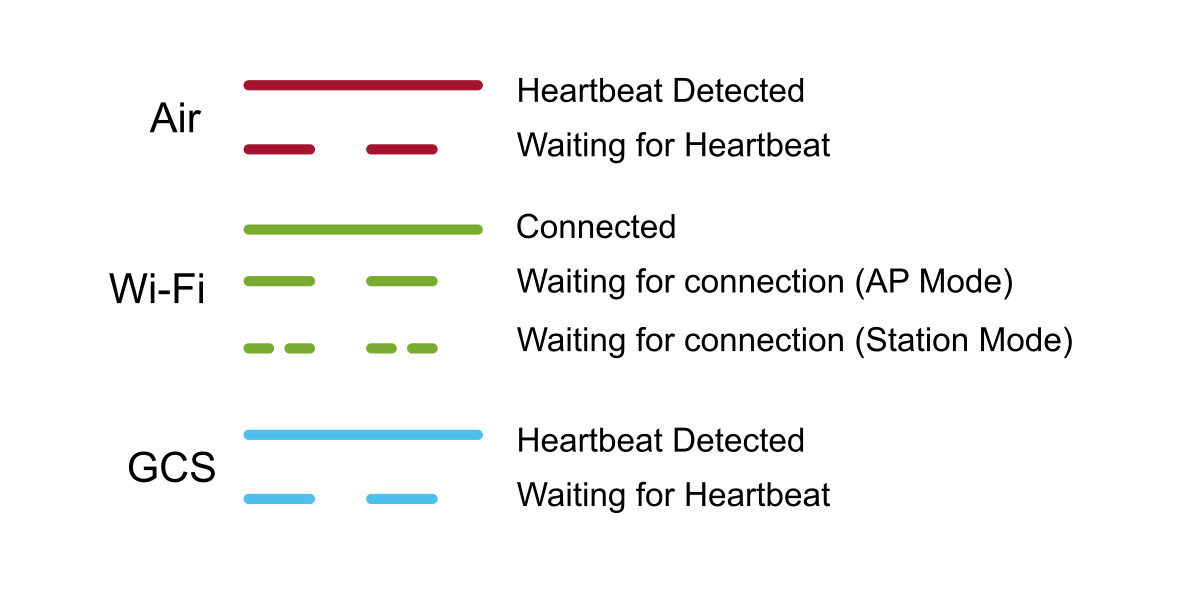
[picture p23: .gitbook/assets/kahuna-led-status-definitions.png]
<figure><figcaption><p>LED Status Definitions*</p></figcaption></figure>

\*Kahuna V1.1 have GCS and Air labels swapped.

## Specifications

| Mass | 4g |
| --- | --- |
| Max output power | 20 dBm (\~112 mW) |
| Range | 2500 m |
| Voltage input | 5V |
| Current Continuous | 20 mA |
| Current Peak | 250 mA |

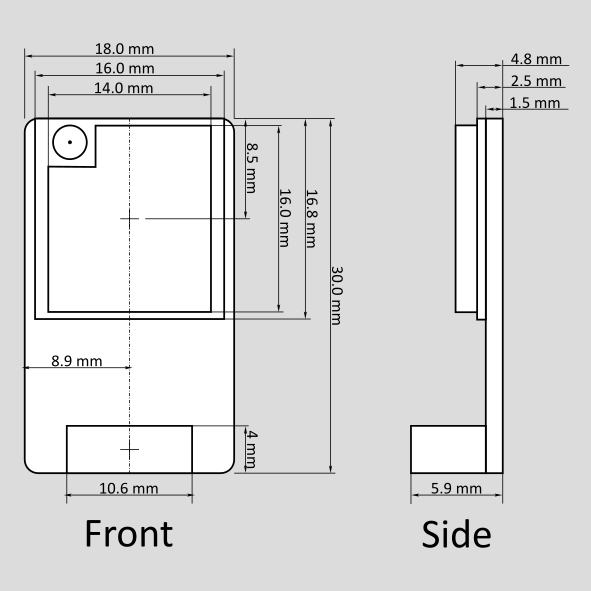
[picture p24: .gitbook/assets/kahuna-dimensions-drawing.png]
<figure><figcaption><p>Physical Dimensions of the Kahuna</p></figcaption></figure>

{% file src="../.gitbook/assets/kahuna-v1.2.step" %}
CAD file for the Kahuna
{% endfile %}

## 3D Printed Case

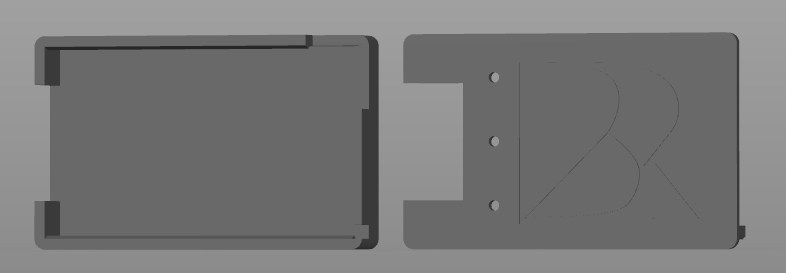
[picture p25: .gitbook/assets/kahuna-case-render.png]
<figure><figcaption><p>Render of Case</p></figcaption></figure>

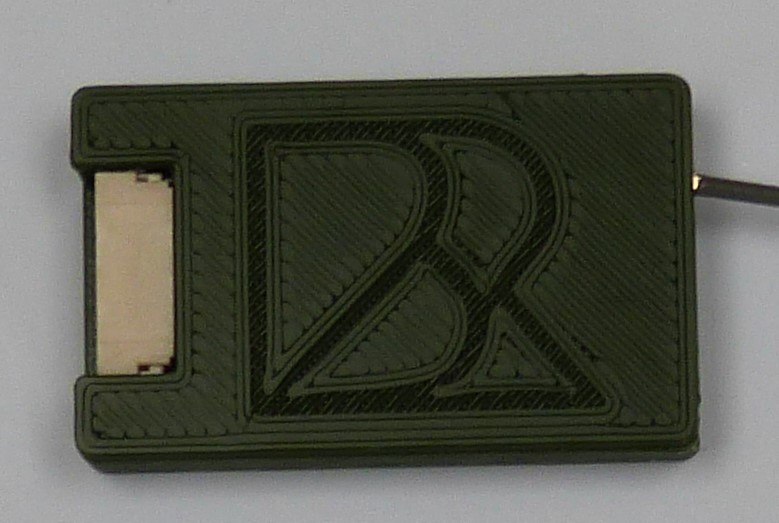
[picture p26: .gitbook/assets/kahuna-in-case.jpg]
<figure><figcaption><p>Kahuna in Case</p></figcaption></figure>

Files are available to download and print here:

{% file src="../.gitbook/assets/kahuna-case-top.stl" %}

{% file src="../.gitbook/assets/kahuna-case-base.stl" %}

If you want to edit the parts, the raw files are here:

{% file src="../.gitbook/assets/kahuna-case-top.sldprt" %}

{% file src="../.gitbook/assets/kahuna-case-base.sldprt" %}

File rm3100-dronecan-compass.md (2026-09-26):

# RM3100 DroneCAN Compass

## Introduction

The RM3100 DroneCAN Compass Node uses the [PNI RM3100 Magnotometer](https://www.pnisensor.com/rm3100/) and sends compass messages over DroneCAN back to a flight controller. The node works on a regular DroneCAN bus and is completely plug and play.

<figure><figcaption></figcaption></figure>

### Features 

* STM32L431 Processor - Fast and Capable
* PNI RM3100 Magnetometer - Highly accurate and low cost
* Over and Under Voltage Protection - Prevents adverse readings during surges&#x20;
* Over Current Protection - Prevents CAN bus interference in case of node failure
* Reverse Polarity Protection
* ESD Protection
* Enable-able CAN Terminating Resistor
* Pixhawk Standard JST-GH Connector
* Pads for I2C, Serial and CAN Interfaces Exposed

## Specifications

* Typical 22mA (4.5 - 5.5 V)
* 25 x 25 mm, \~ 6g Mass
* M2 Mounting Holes
* Temp Range: -40 °C to +85 °C

### Pinout 

The JST-GH 4 Pin connector on the top of the board is pinned out using the Pixhawk convention:

| Pin | Function |
| --- | --- |
| 1 | 5V |
| 2 | CAN H |
| 3 | CAN L |
| 4 | GND |

## Parameters

The following parameters should be used for the Flight Controller. For an initial set up, plug the Node into CAN1 on your flight controller and set the following parameters.

| Parameter | Value |
| --- | ----- |
| CAN\_P1\_DRIVER | 1 |
| CAN\_D1\_PROTOCOL | 1 |

For advanced compass configurations on ardupilot, refer to these [instructions](https://ardupilot.org/copter/docs/common-compass-setup-advanced.html).

## Mechanical

Mechanical design of the PCB and STEP file.

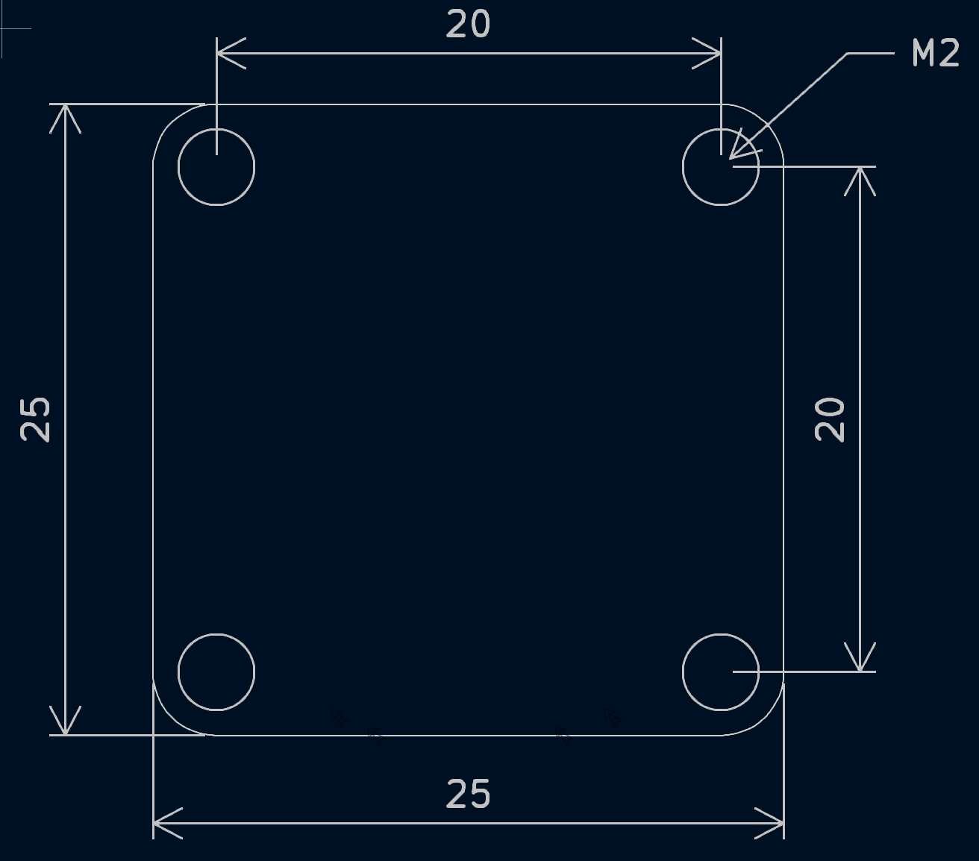
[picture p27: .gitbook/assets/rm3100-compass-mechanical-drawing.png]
<figure><figcaption></figcaption></figure>

{% file src=".gitbook/assets/rm3100-compass.step" %}

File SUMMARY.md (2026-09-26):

# Table of contents

* [Beyond Robotix Documentation](README.md)
* [Heated Pitot](heated-pitot/README.md)
  * [Parameters](heated-pitot/parameters.md)
  * [Telemetry](heated-pitot/telemetry.md)
* [Kahuna](kahuna/README.md)
  * [Quick Start Guide](kahuna/quick-start-guide.md)
  * [Further Configuration](kahuna/further-configuration.md)
  * [INAV Setup](kahuna/inav-setup.md)
  * [Hardware](kahuna/hardware.md)
  * [Firmware Update](kahuna/firmware-update.md)
  * [Troubleshooting](kahuna/troubleshooting.md)
* [CAN Ecosystem](can-ecosystem/README.md)
  * [Node Development Board V1.0](can-ecosystem/node-development-board-v1.0.md)
  * [Node Development Board V1.1](can-ecosystem/node-development-board-v1.1.md)
  * [Micro Node](can-ecosystem/micro-node.md)
  * [CAN Node](can-ecosystem/l431-can-node.md)
  * [CAN Node Plus](can-ecosystem/can-node-plus.md)
  * [Arduino DroneCAN](can-ecosystem/arduino-dronecan/README.md)
    * [Thermocouple Tutorial](can-ecosystem/arduino-dronecan/thermocouple-tutorial.md)
  * [AP Periph](can-ecosystem/ap-periph.md)
* [Air Data Module](air-data-module/README.md)
  * [Quick Start Guide](air-data-module/quick-start-guide.md)
  * [Air Data Module Mini](air-data-module/air-data-module-mini.md)
  * [Air Data Moulde Original](air-data-module/air-data-moulde-original.md)
* [RM3100 DroneCAN Compass](rm3100-dronecan-compass.md)
* [Core Autopilot](core-autopilot/README.md)
  * [Core Pinout](core-autopilot/core-pinout.md)
  * [Default Carrier](core-autopilot/default-carrier-pinout.md)
  * [Core Power](core-autopilot/core-power.md)
  * [Advanced Configuration](core-autopilot/core-advanced-configuration.md)
* [Engineering Change Notice](engineering-change-notice.md)

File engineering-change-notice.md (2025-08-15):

---
description: >-
  Notification of any hardware changes to our products. For software, please see
  the relevant Github release notes.
---

# Engineering Change Notice

## Micro CAN Node development board

### V1.1 release

Moving forward, CAN node development boards will be V1.1. The V1.0 boards can be purchased on special request, and we will have a limited stock immediately available for the time being.&#x20;

V1.1 improves on flexibility for development, exposing more GPIO pins and providing more 3.3V and 5V pin access. The board is slightly bigger to accommodate this change, as such the mounting holes have also moved position. The SPI port is no longer accessible via JSTGH but can be accessed through the GPIO pads instead. &#x20;

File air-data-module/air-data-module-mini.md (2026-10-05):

---
description: Improve design of the Air Data Module - Compact and Reliable
---

# Air Data Module Mini

The Air Data Module Mini is an all in one board that reads airspeed and barometric altitude and outputs over DroneCAN. The module has a number of protection features including over-current protection, over and under-voltage protections, reverse polarity protection and ESD protection.

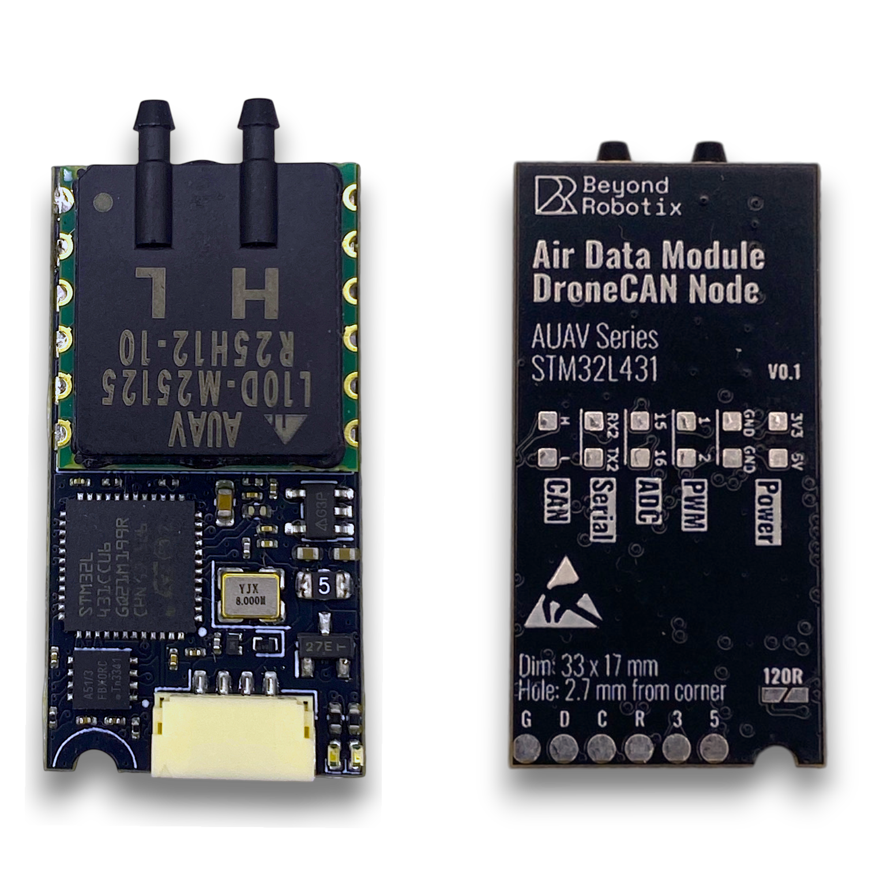
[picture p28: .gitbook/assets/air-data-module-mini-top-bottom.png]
<figure><figcaption></figcaption></figure>

## Specifications

* Mass: 3.8 g (Sensor module only)
* Dimensions: 33x17mm
* Power: 21mA (4.5 - 5.5 V)
* Operating Temperature: -40 °C to +85 °C
* Absolute Pressure Operating Range: 25kPa - 125kPa
* Connector: JST-GH 4 Pin (compatible with Pixhawk and Cube CAN port)

## Pinout

The main connector on the board is a JST-GH with the Pixhawk standard CAN pinout.

<table><thead><tr><th width="316" align="right">Pin</th><th>Function</th><th data-hidden>Notes</th></tr></thead><tbody><tr><td align="right">1</td><td>5V</td><td>Recommended: 4.5 - 6V</td></tr><tr><td align="right">2</td><td>CAN H</td><td></td></tr><tr><td align="right">3</td><td>CAN L</td><td></td></tr><tr><td align="right">4</td><td>GND</td><td></td></tr></tbody></table>

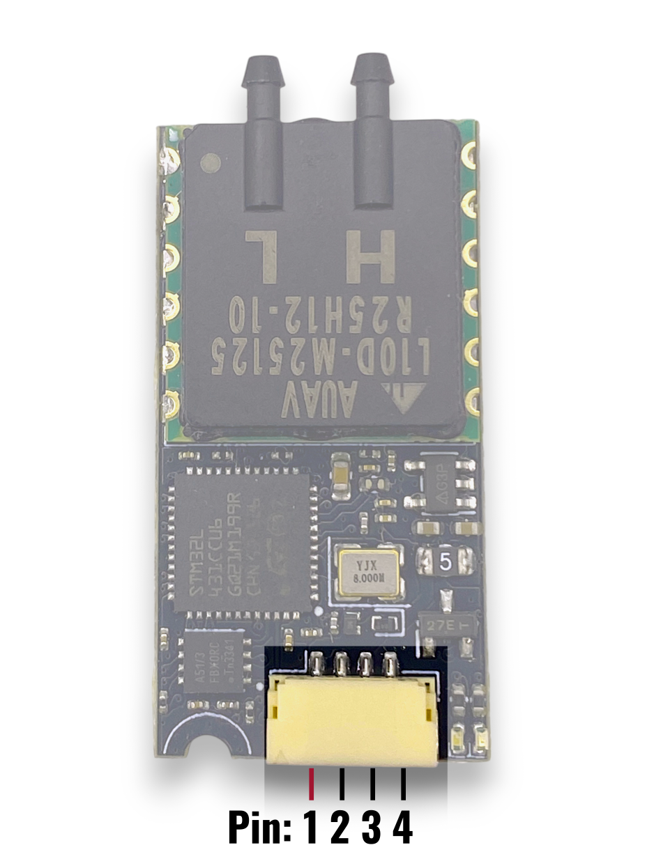
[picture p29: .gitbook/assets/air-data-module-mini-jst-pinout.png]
<figure><figcaption></figcaption></figure>

## Extra Pins

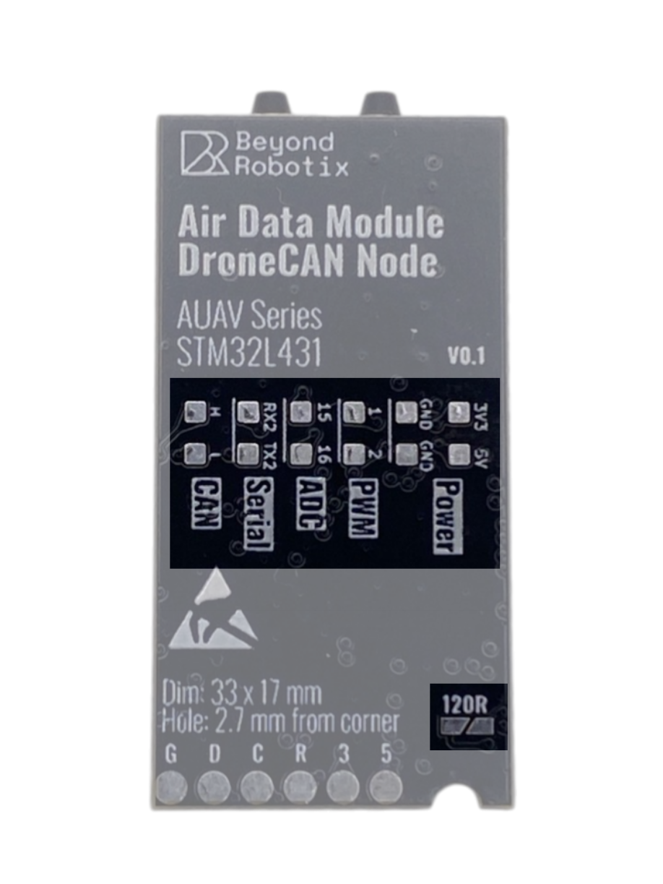
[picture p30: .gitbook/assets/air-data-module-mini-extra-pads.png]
<figure><figcaption></figcaption></figure>

The series of pads on the bottom can be used for other peripheral activities.

* 5V - Direct 5V from the JST-GH after reverse polarity protection
* 3V3 - The 3.3V rail used by the STM32 and the AUAV sensor. You can use it but the peak supply is 500 mA.
* GND - Common ground between all power and logic
* 1 - PWM output from pin 1 of the STM that can be used as standard servo PWM or GPIO\*
* 2 - PWM output from pin 2 of the STM that can be used as standard servo PWM or GPIO\*
* 15 - ADC input to pin 15 of the STM, can also be a GPIO\*
* 16 - ADC input to pin 16 of the STM, can also be a GPIO\*
* RX2 - **Serial2** receive (input) from the STM
* TX2 - Serial2 transmit (output) from the STM
* H - CAN H output of the CAN transceiver - Common with JST-GH
* L - CAN L output of the CAN transciever - Common with JST-GH
* 120R - Jumper to enable the 120 Ohm terminating resistor between CAN H and CAN L (not enabled by default)

The circle pads are used for programming.

## Mechanical

A mechanical drawing of the Air Data Module Mini along with a step file. The pitot-static tube CAD can be found [here](https://grabcad.com/library/pitot-tube-5).

<figure><figcaption></figcaption></figure>

{% file src="../.gitbook/assets/air-data-module-mini-mechanical-drawing.pdf" %}

{% file src="../.gitbook/assets/air-data-module-mini.step" %}

## Firmware

Below are the binaries that can be used to flash the Air Data Module Mini. You can upload the firmware in Mission Planner or DroneCAN GUI.

{% hint style="danger" %}
Make sure you put the correct firmware on your Air Data Module Mini - Check your AUAV Sensor to see which version you need. No error will show if you upload the wrong firmware, but your airspeed reading will be incorrect.
{% endhint %}

{% file src="../.gitbook/assets/BeyondRobotix_AUAVL05D.bin" %}

{% file src="../.gitbook/assets/BeyondRobotix_AUAVL10D.bin" %}

{% file src="../.gitbook/assets/BeyondRobotix_AUAVL30D.bin" %}

{% file src="../.gitbook/assets/BeyondRobotix_AUAVL60D.bin" %}

{% file src="../.gitbook/assets/BeyondRobotix_AUAVL100D.bin" %}

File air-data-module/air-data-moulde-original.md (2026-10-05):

# Air Data Moulde Original

<figure><figcaption></figcaption></figure>

The Air Data Module is made up of two layers of PCBs, the lower layer is the Beyond Robotix Micro CAN node and the upper layer is the Air Data Module layer. The two layers interconnect using a high density connector. The Air Data module comes in a PLA Case, with 200mm of hose and a pitot-static tube.

## Pinout

<table><thead><tr><th width="316" align="right">Pin</th><th>Function</th><th data-hidden>Notes</th></tr></thead><tbody><tr><td align="right">1</td><td>5V</td><td>Recommended: 4.5 - 6V</td></tr><tr><td align="right">2</td><td>CAN H</td><td></td></tr><tr><td align="right">3</td><td>CAN L</td><td></td></tr><tr><td align="right">4</td><td>GND</td><td></td></tr></tbody></table>

{% hint style="info" %}
The CAN ports are common that can be used to daisy chain to other CAN nodes.
{% endhint %}

The computation on the Air Data Module is performed on the [CAN Node](../can-ecosystem/micro-node.md). If you would like to terminate the CAN bus at the Air Data Module, a solder jumper labeled `120R` can be jumped.

<figure><figcaption></figcaption></figure>

## Parameters

| Parameter | Description | Accepted Values |
| --- | --- | --- |
| NodeID | The ID the node will appear as in the CAN bus | 1-127 |
| Sensor\_Pressure | This is the type of AUAV sensor installed on the Air Data Module. | <p>L05D = 5<br>L10D = 10<br>L30D = 30<br>L60D = 60<br>L100D = 100</p> |

{% hint style="info" %}
Newer versions are now shipped with AP\_Periph (Ardupilots peripheral firmware). This will have the parameter built into the firmware so it cannot be changed.
{% endhint %}

## Firmware

Our air data module runs on custom firmware which can be found here, including the latest firmware binaries:

{% hint style="danger" %}
Make sure you put the correct firmware on your Air Data Module - Check your AUAV Sensor to see which version you need. No error will show if you upload the wrong firmware, but your airspeed reading will be incorrect.
{% endhint %}

{% file src="../.gitbook/assets/BeyondRobotix_AUAVL05D (1).bin" %}

{% file src="../.gitbook/assets/BeyondRobotix_AUAVL10D (1).bin" %}

{% file src="../.gitbook/assets/BeyondRobotix_AUAVL30D (1).bin" %}

{% file src="../.gitbook/assets/BeyondRobotix_AUAVL60D (1).bin" %}

{% file src="../.gitbook/assets/BeyondRobotix_AUAVL100D (1).bin" %}

To update to the latest firmware, there are two methods you can use:

* Mission Planner
* DroneCAN GUI

### Updating: Mission Planner

1. Connect to your Flight Controller in Mission Planner
2. Go to Setup > Optional Hardware > UAVCAN
3. Click `CAN1` or `CAN2` (Depending on the bus you are connected to)
4. Click on `Menu` next to the Air Data Module
5. Click Update Firmware
6. Select the `.bin` file from the latest release page above

### Updating: DroneCAN GUI

1. Connect to your Flight Controller in DroneCAN GUI
2. Double Click on the Air Data Module
3. Click Update Firmware
4. Select the `.bin` file from the latest release page above

You are now on the latest version of the firmware!

## Mechanical

Images of hole spacing and overall dimensions are provided below. Additionally, the case STL files can

### Case Specifications

<figure><figcaption></figcaption></figure>

Specifcations for the size and shape of the case:

{% file src="../.gitbook/assets/air-data-module-case-mechanical-drawing.pdf" %}

Files to 3D print/edit the included case:

{% file src="../.gitbook/assets/air-data-module-case-lid.3mf" %}

{% file src="../.gitbook/assets/air-data-module-case-base.3mf" %}

{% file src="../.gitbook/assets/air-data-module-case-lid.step" %}

{% file src="../.gitbook/assets/air-data-module-case-base.step" %}

### PCB Specifications

{% file src="../.gitbook/assets/air-data-module-pcb-mechanical-drawing.pdf" %}

{% file src="../.gitbook/assets/air-data-module-pcb.step" %}

Please note: this product is designed to require the case. Without it, the Micro CAN node will need mechanically stabilising through another means.

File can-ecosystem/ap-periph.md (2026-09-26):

---
description: Contains information relevant to using AP periph on the micro node system
icon: robot-astromech
---

# AP Periph

We support AP\_Periph based firmware's for our CAN node. The Nodes ship with a generic AP\_periph firmware by default.

## Default firmware features

* 6 PWMs/GPIOs
  * PA0 - PWM 1 - GPIO 50
  * PA1 - PWM 2 - GPIO 51
  * PA8 - PWM 3 - GPIO 52
  * PA9 - PWM 4 - GPIO 53
  * PA10 - PWM 5 - GPIO 54
  * PA11 - PWM 6 - GPIO 55
* Serial UBLOX/NMEA/SBF GPS (Serial 3 by default)
* Barometers
* Airspeed
* Battery (any, but ADC PA0 voltage and PA1 Current enabled by default)
* Relay

## Firmware files and flashing

If there is no AP periph bootloader present on the node (you've been using Arduino DroneCAN for example) then AP\_Periph\_with\_bl.hex needs flashing with STM cube Programmer using STLINK or UART.&#x20;

If the AP periph bootloader is present, the .bin file can be used in the usual way through mission planner.

{% hint style="info" %}
We've working on merging our hwdef file into Ardupilot repository
{% endhint %}

{% file src="../.gitbook/assets/AP_Periph.bin" %}

{% file src="../.gitbook/assets/ap-periph-firmware-with-bootloader.hex" %}

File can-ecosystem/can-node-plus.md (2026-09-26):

---
description: Our H7 CAN node, with two independent CAN FD interfaces
icon: microchip
---

# CAN Node Plus

## Overview

The CAN Node Plus steps up from our L431 nodes to an STM32H723. It brings two fully independent CAN FD interfaces, considerably more processing power, and a set of JST-GH connectors following the same conventions as an autopilot, so standard peripherals plug straight in.

Like the rest of the range it runs [Arduino DroneCAN](arduino-dronecan/), so you write a normal Arduino sketch and get DroneCAN, parameters and firmware update over CAN for free.

<figure><figcaption></figcaption></figure>

{% embed url="https://www.beyondrobotix.com/products/can-node-plus" %}

* STM32H723VGHx processor - 550 MHz Cortex-M7, 1 MB flash
* **2x independent CAN FD interfaces**, each with its own transceiver and its own JST-GH connector
* Optional 120 ohm termination on each CAN interface, via a solder jumper
* USB-C
* SWD + serial debug header for easy Arduino DroneCAN development
* JST-GH connector interfaces
  * 2x CAN
  * 1x Serial with flow control
  * 1x Serial + I2C combined, in the same pinout an autopilot uses for GPS
  * 1x SPI, with two chip selects and two data ready lines
  * 1x PWM, 8 channels
* On-board I2C pull-up resistors
* 5V peripheral rail is current limited to about 540 mA, and can be switched off in software
* Input voltage monitoring
* BOOT0 button
* Power input from either CAN connector or from USB, each individually fused
* 32 x 32mm, with 4x M3 mounting holes on a 25 x 25mm square

<div><figure><figcaption><p>Top - the two CAN connectors (<code>C1</code>, <code>C2</code>), Serial 1 (<code>S1</code>), Serial 2 + I2C (<code>S2+I2C</code>), the debug header and the BOOT button</p></figcaption></figure> <figure><figcaption><p>Bottom - USB-C, SPI, PWM, the <code>JP1</code> power bridge and the two <code>TERM</code> termination jumpers</p></figcaption></figure></div>

## Mechanical

### CAD

Full CAD including connectors can be found here:

{% file src="../.gitbook/assets/can-node-plus.step" %}

### Mounting holes & Board dimensions

The board is 32 x 32mm, with the four mounting holes on a 25 x 25mm square. Mounting holes are M3 (3.2mm diameter cutout).

Dimensions in mm:

<figure><figcaption></figcaption></figure>

## Power

The board takes power from three places: CAN1, CAN2 and USB. Each one goes through its own 1 A fuse and then its own diode onto a single internal 5V bus, so the three are OR'd together rather than switched between - whichever input is highest at the time carries the load. The diodes double as reverse protection on each input.

Everything on the board runs from that shared bus: both CAN transceivers, the 3.3V regulator that supplies the processor, and the switched 5V rail that feeds the peripheral connectors.

<figure><figcaption><p>Three fused and OR'd inputs onto one 5V bus</p></figcaption></figure>

### Redundancy

The OR'ing is passive, which is what makes it useful on a vehicle where the node has to stay up:

* **Either CAN connector can power the whole board**, both transceivers included. A node wired to two buses keeps running, on both interfaces, when one bus loses power.
* **Changeover is instant and needs no firmware.** There is no switching logic to configure, and none to fail - if the input carrying the load disappears, the next highest simply takes over.
* **A fault on one input can't propagate.** That input's fuse blows on its own, and its diode blocks the fault from back feeding, so a shorted CAN harness can't drag down the other bus or the flight controller's rail.
* **A second supply can be connected or removed while the node is running**, without disturbing the one already carrying it.

{% hint style="info" %}
The two CAN connectors are separately fused, so by default 5V does **not** pass between them - a peripheral plugged into one won't be fed from the other. `JP1`, on the underside between the two CAN transceivers, bridges them if you want to daisy chain power through the node.

`JP1` joins the two connector pins directly, ahead of both fuses. The node's own supply stays fused either way, but current passing straight through from one connector to the other is not, so size the protection upstream accordingly.
{% endhint %}

### Powering from a flight controller on USB

{% hint style="warning" %}
**A flight controller running on USB alone may not power the node well enough to transmit CAN frames.**

Each CAN input passes through a protection diode, which drops the incoming voltage. A flight controller powered only over USB already puts out a reduced 5V on its CAN connectors, and after our diode the rail can end up below what the CAN transceivers need to drive the bus. The node powers up and runs, so it looks fine, but frames don't go out and it never appears on the bus.

Either of these fixes it:

* Plug USB into the CAN Node Plus as well, so the node has its own supply
* Power the flight controller properly, through `POWER1` or `POWER2`, which brings the CAN rail back up

This bites most often on the bench, where a flight controller on a USB cable is the natural way to work. On a vehicle with a power module fitted it doesn't arise.
{% endhint %}

### The 5V peripheral rail

The peripheral connectors - Serial 1, Serial 2 + I2C, SPI and PWM - aren't fed from the shared bus directly. They come off it through a current limited load switch. If a sensor shorts, the switch limits the current rather than letting it pull the bus down, so the processor keeps running and the node stays on CAN. A failed peripheral doesn't take the node off the bus with it.

**The limit is about 540 mA**, shared across all four connectors - so a GPS on Serial 2 + I2C and a servo rail on PWM are drawing from the same allowance. That sits inside the 1 A input fuse, with the node's own consumption to fit alongside it, so a peripheral taking its full share won't cost you the input. Anything hungrier than the rail can supply wants its own power, not the node's.

Note that `JP2` takes Serial 2 + I2C pin 1 off this rail: in the 3.3V position that pin is fed from the 3.3V regulator that also supplies the processor, so it is neither switched by `PA5` nor covered by the 540 mA limit.

The enable line is `PA5`, held high by a pull-up, so the rail is live as soon as the board is powered and firmware doesn't have to switch it on. Drive it low to cut peripheral power:

```cpp
pinMode(PA5, OUTPUT);
digitalWrite(PA5, LOW);   // peripheral 5V off
digitalWrite(PA5, HIGH);  // and back on
```

That gives you a way to power cycle a hung sensor in flight, without power cycling the vehicle.

{% hint style="info" %}
The load switch's fault output isn't wired to the processor, so firmware can't be told that the limit has tripped. An overcurrent shows up as the peripheral going quiet, not as a flag you can read.
{% endhint %}

### Monitoring the input voltage

The 5V bus is brought to `PB1` through a 10k/10k divider, so a reading on `PB1` is half the bus voltage. Reporting that over DroneCAN is a cheap way to catch a supply that is sagging - which, as above, is what a node that powers up but won't transmit looks like.

## Pinout / Interfaces

### CAN

Two entirely separate CAN FD interfaces, each with its own transceiver and connector. They are not two connectors on one bus - see [two CAN ports](arduino-dronecan/#two-can-ports) for how to use both from one program.

Both connectors are on the bottom edge of the top side, marked `C1` and `C2`, and share the same pinout:

If the node runs but never appears on the bus, check how the other end is powered - see [powering from a flight controller on USB](#powering-from-a-flight-controller-on-usb).

| Pin | Description |
| --- | --- |
| 1 | Vcc (5V) |
| 2 | CANH |
| 3 | CANL |
| 4 | GND |

Each interface has its own 120 ohm termination resistor, fitted by bridging a solder jumper. The jumpers are on the underside of the board, one beside each CAN transceiver, both marked `TERM`. Both are open by default, so terminate only the nodes at the two ends of your bus.

### Serial 1

Serial with flow control, in the same pinout an autopilot uses for telemetry. Marked `S1` on the board, and available in your code as `Serial1`.

| Pin | Description | Processor pin |
| --- | --- | --- |
| 1 | Vcc (5V) | |
| 2 | TX | PD5 |
| 3 | RX | PD6 |
| 4 | CTS | PD3 |
| 5 | RTS | PD4 |
| 6 | GND | |

### Serial 2 & I2C

Serial and I2C brought out on one connector, in the same pinout an autopilot uses for GPS - so a GPS + compass module plugs straight in. Marked `S2+I2C` on the board, and available in your code as `Serial2` and `Wire`.

| Pin | Description | Processor pin |
| --- | --- | --- |
| 1 | Vcc | |
| 2 | TX | PC10 |
| 3 | RX | PC11 |
| 4 | SCL | PB10 |
| 5 | SDA | PB11 |
| 6 | GND | |

I2C pull-up resistors are fitted on the board, so I2C sensors work without adding your own.

{% hint style="info" %}
Pin 1 of this connector is 5V by default, from the switched [peripheral rail](#the-5v-peripheral-rail). `JP2`, on the top side just below the connector, switches it to 3.3V if your peripheral needs that instead - which also takes it off that rail, onto the processor's own 3.3V regulator.
{% endhint %}

### SPI

Two chip selects, two data ready inputs, plus sync and reset lines. On the underside of the board, and available in your code as `SPI`, with the control lines as named pins.

| Pin | Description | Processor pin | In your code |
| --- | --- | --- | --- |
| 1 | Vcc (5V) | | |
| 2 | SCK | PE2 | `SPI` |
| 3 | MISO | PE5 | `SPI` |
| 4 | MOSI | PE6 | `SPI` |
| 5 | CS1 | PD15 | `SPI_CS1` |
| 6 | CS2 | PD14 | `SPI_CS2` |
| 7 | SYNC | PD13 | `SPI_SYNC` |
| 8 | DRDY1 | PD12 | `SPI_DRDY1`  |
| 9 | DRDY2 | PD11 | `SPI_DRDY2`  |
| 10  | nRESET | PD10 | `SPI_nRESET` |
| 11  | GND | | |

The chip select, data ready, sync and reset lines are plain GPIO - drive or read them yourself, for example `digitalWrite(SPI_CS1, LOW)`.

### PWM

8 PWM channels on one connector, on the underside of the board opposite the SPI connector.

| Pin | Description | Processor pin | In your code |
| --- | --- | --- | --- |
| 1 | Vcc (5V) | | |
| 2 | PWM 1 | PA3 | `PWM1` |
| 3 | PWM 2 | PA2 | `PWM2` |
| 4 | PWM 3 | PA1 | `PWM3` |
| 5 | PWM 4 | PE13 | `PWM4` |
| 6 | PWM 5 | PA9 | `PWM5` |
| 7 | PWM 6 | PA8 | `PWM6` |
| 8 | PWM 7 | PC7 | `PWM7` |
| 9 | PWM 8 | PC6 | `PWM8` |
| 10  | GND | | |

{% hint style="info" %}
Use the names rather than the processor pins in your code - `analogWrite(PWM1, value)` - and the numbering follows the connector.
{% endhint %}

## Programming the board

### ST-LINK

STM32 allows the ability to easily debug programs over SWDIO. This allows live variable inspection, breakpoints and more - which makes program development much easier!

The debug header carries SWD, reset, and a serial console which appears in your code as `Serial`. To upload code:

1. Connect the node to your ST-LINK
2. Click upload or debug in VS-Code!

The header is shrouded and keyed, so the cable only fits one way round - there is no pin 1 to line up by eye.

| Pin | Description |
| --- | --- |
| 1 | NC |
| 2 | NC |
| 3 | 3.3V |
| 4 | SWD |
| 5 | GND |
| 6 | SWC |
| 7 | GND |
| 8 | NC |
| 9 | NC |
| 10  | NC |
| 11  | GND |
| 12  | NRST |
| 13  | Debug UART RX (into the node) |
| 14  | Debug UART TX (out of the node) |

{% hint style="warning" %}
Pin 3 is **3.3V**, not 5V as on the Micro Node debug header - this header will not power the board. Power the node over CAN or USB while debugging.
{% endhint %}

### DFU

There is a BOOT0 button on the board. Holding it while resetting the node starts the processor's built in bootloader, which can be used to recover a board over USB if the bootloader is ever lost.

## Using it with Arduino DroneCAN

Build for the CAN Node Plus by selecting the `Micro-Node-Plus-App` environment in PlatformIO. Everything else works the same as on the rest of the range, with two additions this board is capable of: CAN FD, and running both CAN interfaces at once.

{% content-ref url="arduino-dronecan/" %}
[arduino-dronecan](arduino-dronecan/)
{% endcontent-ref %}

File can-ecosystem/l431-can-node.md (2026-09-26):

---
description: A standalone STM32L431 CAN node for converting sensors to DroneCAN
icon: split
---

# CAN Node

## Overview

This is a standard form factor variant of our Micro Node for projects which require less customisability but still with lots of features accessible, and the handy debug port for developing Arduino DroneCAN applications.

With its mounting holes & 2.54mm header it can be integrated robustly into your projects.

{% embed url="https://www.beyondrobotix.com/products/can-node" %}

* Debug interface for easy Arduino DroneCAN development (Serial+SWD)
* M2 18x20mm mounting holes
* LED indicators
* JST-GH connector interfaces
  * 1x CAN interface with two CAN connectors for daisy chaining
  * 1x Serial
  * 1x i2c
* 2.54mm pitch general breakouts including:
  * CAN (same interface as the JST-GH)
  * Additional serial
  * 5 ADCs
  * 6 PWMs
  * i2c (same interface as JST-GH)
  * 5v
  * 3.3v
* Power input dioded + fused

<div><figure><figcaption></figcaption></figure> <figure><figcaption></figcaption></figure></div>

## Specifications

| Item | Detail |
| --- | --- |
| MCU | STM32L431 |
| Flash | 256 KB total |
| CAN | 1x CAN1 (Classic CAN, no CAN FD) |
| Crystal | 8 MHz external oscillator |
| Dimensions | 18 x 20 mm (see [Mounting holes & Board dimensions](l431-can-node.md#mounting-holes-and-board-dimensions)) |

## Firmware

The board is primarily designed to be used with our **Arduino DroneCAN** library, so you can write your own firmware around your sensor with minimal boilerplate. It also ships with **AP\_Periph** firmware by default, ArduPilot's ready-made DroneCAN peripheral firmware, for when no custom firmware is needed.

### Arduino DroneCAN

The recommended way to build custom firmware for this board. Handles the DroneCAN plumbing for you, so integrating a new sensor is usually a small amount of code.

{% content-ref url="arduino-dronecan/" %}
[arduino-dronecan](arduino-dronecan/)
{% endcontent-ref %}

### AP\_Periph (default shipped firmware)

Every board ships with a generic AP\_Periph build by default. It requires no code and supports a wide range of common sensors out of the box.

#### Default firmware features

* **Servo/PWM output** — 6 channels, see [PWM](l431-can-node.md#pwm) below
* **GPS** — moving-baseline support, Septentrio SBF driver enabled, output on Serial 3 by default
* **Airspeed (I2C)** — MS4525 sensor as default type
* **Battery monitor** — analog voltage/current sensing, disabled by default, enable via DroneCAN parameters
* **Relay output**
* **Serial ESC passthrough**

#### Servo / PWM outputs (channels 1–6)

| Pin  | RCOut Channel (OUTn\_) |
| ---- | --- |
| PA0  | 1 |
| PA1  | 2 |
| PA8  | 3 |
| PA9  | 4 |
| PA10 | 5 |
| PA11 | 6 |

Outputs 1–2 are driven by TIM2 (general-purpose timer), outputs 3–6 by TIM1 (advanced timer).

| Parameter | Purpose | Notes |
| --- | --- | --- |
| `OUTn_FUNCTION` | Assigns output function to channel _n_ (1–6) | `0` = Disabled. See `SRV_Channel::Aux_servo_function_t` for full list (e.g. Motor1, RCIN1, GPIO). |
| `OUTn_MIN` / `OUTn_MAX` | PWM endpoint range (µs) | Per channel |
| `OUTn_TRIM` | Trim/neutral PWM (µs) | Per channel |
| `OUTn_REVERSED` | Reverse output direction | Per channel |
| `ESC_RATE` | Update rate for ESC/motor outputs | Default 400 Hz |
| `ESC_PWM_TYPE` | Output protocol (OneShot/DShot/etc.) | Default 0 (normal PWM) |

Relay/GPIO output can reuse these same pins (GPIO 50–55) when the corresponding `OUTn_FUNCTION` is set to `-1`/GPIO instead of a servo function.

### ADC

The following pins can be used as ADCs. The channel is what is used to identify the pin in AP\_Periph, for example for the `BATT_VOLT_PIN`&#x20;

| Hardware Pin | ADC Channel |
| --- | --- |
| A0 | `5` |
| A1 | `6` |
| A4 | `9` |
| B0 | `15` |
| B1 | `16` |

{% hint style="danger" %}
The maximum voltage of the ADC pins is 3.3V.
{% endhint %}

#### Battery monitor

| Parameter | Purpose | Default |
| --- | --- | --- |
| `BATT_MONITOR` | Monitor type (`0`=Disabled, `4`=Analog Voltage+Current, etc.) | `0` (disabled) |
| `BATT_VOLT_PIN` | ADC pin for voltage sense | `5` (maps to PB0) |
| `BATT_VOLT_MULT`  | Voltage divider scale | `21.0` |
| `BATT_CURR_PIN` | ADC pin for current sense | `6` (maps to PB1) |
| `BATT_AMP_PERVLT` | Current sensor scale (A/V) | `40.0` |

Set `BATT_MONITOR` to a nonzero type to enable; the pin/scale defaults above already match the onboard sense resistors/divider, but can be overridden per-install if a different sensor is wired.

#### Airspeed (I2C)

| Parameter | Purpose | Default |
| --- | --- | --- |
| `ARSPD_TYPE` | Sensor type | `1` = MS4525 |
| `ARSPD_BUS`  | I2C bus index | Auto-detected on the onboard I2C bus |

#### GPS

| Parameter | Purpose | Default |
| --- | --- | --- |
| `GPS1_TYPE` | GPS protocol/type | Auto-detect on Serial 3 |
| `GPS_PORT` | DroneCAN GPS output port index | `2` |
| `GPS_MB_ONLY_PORT` | Restrict moving-baseline pairing to a specific CAN port | `0` (disabled) |

Moving-baseline and Septentrio SBF support are compiled in; no extra param is needed to enable the driver itself, only to select the correct `GPS1_TYPE`.

#### Firmware files and flashing

If there is no AP\_Periph bootloader present on the node (you've been using Arduino DroneCAN, for example) then the `with bootloader` .hex needs flashing with STM32CubeProgrammer using STLINK or UART.

If the AP\_Periph bootloader is already present, the .bin file can be used in the usual way through Mission Planner.

{% file src="../.gitbook/assets/can-node-v1.0-ap-periph.bin" %}

{% file src="../.gitbook/assets/can-node-v1.0-ap-periph-with-bootloader.hex" %}

For general background on AP\_Periph on our nodes, see:

{% content-ref url="ap-periph.md" %}
[ap-periph.md](ap-periph.md)
{% endcontent-ref %}

## Mechanical

### CAD

Full CAD including connectors can be found here:

{% file src="../.gitbook/assets/can-node-v1.0.step" %}

### Mounting holes & Board dimensions

Mounting holes are M2 (2.2mm diameter cutout)

Dimensions in mm:

<figure><figcaption></figcaption></figure>

## Pinout / Interfaces

### CAN

The CAN Node has 1 available CAN interface, which is pinned out to 2 JST-GH CAN ports, to allow CAN device chaining.

| Pin Number | Description |
| --- | --- |
| 1 | Vcc (5V) |
| 2 | CANH |
| 3 | CANL |
| 4 | GND |

### I2C

The CAN Node has 1 available I2C interface exposed to a JST-GH port.

{% hint style="warning" %}
The CAN Node V1.0 has no i2c pullups on board. I2C sensors attached to this interface will need pullups to function.
{% endhint %}

| Pin | Description |
| --- | --- |
| 1 | 5V |
| 2 | SCL |
| 3 | SDA |
| 4 | GND |

{% hint style="info" %}
The pins in the I2C JST-GH are common (the same interface) with the pins on the 2.54 mm header pins.
{% endhint %}

### Serial

The CAN node has 3 serial interface exposed. UART1 is exposed on the 2.54mm header pins, UART2 is exposed in the ST-LINK Debug header and UART3 is exposed on the JST-GH.

| Pin | Description |
| --- | --- |
| 1 | Vcc (5V) |
| 2 | UART3\_TX |
| 3 | UART3\_RX |
| 4 | N/C |
| 5 | N/C |
| 6 | GND |

## 2.54 mm Header

More interfaces can be accessed through the 2.54 mm header. Wires could be directly soldered to these pads, or header pins could be added.

The CAN interface is accessible through this header, as well as power input, allowing the board to be used purely through the header without needing the JST-GH connectors if desired.

The following interfaces aer pinned out on the headers:

* CAN interface (C\_L, C\_H)
* Power (5V, 3v3, 2x GND)
* UART1 (TX1, RX1)
* I2C interface (SDA, SCL)
* 9x GPIO/ADC/PWM&#x20;

How to use the GPIO/ADC/PWM pins depends on the firmware. If you are using the default AP\_Periph - see [#ap\_periph-default-shipped-firmware](l431-can-node.md#ap_periph-default-shipped-firmware "mention"). If you are using Arduino DroneCAN - see [#arduino-dronecan](./#arduino-dronecan "mention")

<figure><figcaption></figcaption></figure>

## Programming the board

### ST-Link

STM32 allows the ability to easily debug programs over SWDIO. This allows live variable inspection, breakpoints and more - which makes program development much easier!

The "STLINKV3" header is directly compatible with the [STLINK-V3MINIE](https://www.st.com/en/development-tools/stlink-v3minie.html). To upload code to the CAN Node, simply:

1. Connect the node to the STLINKV3
2. Click upload or debug in VS-Code!

The pins on the ST-LINK header could also be used with normal Arduino jumpers so a STLINKV2, or another SWD based debugger could be used. The pins are as follows:

<figure><figcaption><p>STLINK Header</p></figcaption></figure>

<table><thead><tr><th width="246">Pin Number</th><th>Description</th></tr></thead><tbody><tr><td>1</td><td><mark style="color:orange;">NC</mark></td></tr><tr><td>2</td><td><mark style="color:orange;">NC</mark></td></tr><tr><td>3</td><td>5V in</td></tr><tr><td>4</td><td>SWD</td></tr><tr><td>5</td><td><mark style="color:blue;">GND</mark></td></tr><tr><td>6</td><td>SWC</td></tr><tr><td>7</td><td><mark style="color:blue;">GND</mark></td></tr><tr><td>8</td><td><mark style="color:orange;">NC</mark></td></tr><tr><td>9</td><td><mark style="color:orange;">NC</mark></td></tr><tr><td>10</td><td><mark style="color:blue;">GND</mark></td></tr><tr><td>11</td><td><mark style="color:orange;">NC</mark></td></tr><tr><td>12</td><td><mark style="color:orange;">NC</mark></td></tr><tr><td>13</td><td>UART2_TX</td></tr><tr><td>14</td><td>UART2_RX</td></tr></tbody></table>

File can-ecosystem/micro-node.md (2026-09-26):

---
description: Rappidly integrate a compact CAN enabled STM32 processor
icon: industry
---

# Micro Node

<figure><figcaption><p>Micro Node</p></figcaption></figure>

The Beyond Robotix Micro Node allows you to create production grade PCBs without needing to worry about the complicated bit. Put the board to board connector on your project, wire in a sensor, a connector and now you have a CAN enabled project.

We do Quality Assurance and software upload, meaning you just have to screw the board down to your project.

## Store

{% embed url="https://www.beyondrobotix.com/products/micro-can-node" %}

{% embed url="https://www.beyondrobotix.com/products/micro-can-node-development-bundle" %}

## Specifications

* Dimensions: 26 x 20 mm
* Mass: 2.2 g
* Power Consumption: 30 mA (40 mA peak) at 5V
* STM32L431CCU6 Processor with 256 KB of flash
* 200mA LDO
* Short Circuit Protection - 1 A Input Fuse
* Reverse Polarity Protection - Input Diode
* Optional 120 ohm termination resistor via solder pad
* Status LED
* High reliability connector & mechanical fixing
* Screw heads accessible from the top of the board
* AP periph firmware support
* Arduino DroneCAN support

## Pinout

The Micro Node requires the **DF40C-80DS-0.4V(51)** connector to be on the carrier board.&#x20;

{% embed url="https://www.mouser.co.uk/ProductDetail/Hirose-Connector/DF40C-80DS-0.4V51?qs=eDUdFcBPps3TI2tU7fRYSg%3D%3D" %}
CAN node carrier board connector
{% endembed %}

{% hint style="info" %}
The equivalent JLCPCB component is C312960
{% endhint %}

The footprint can be downloaded from the mouser page. Be sure to use this one! Pin numbers can be different on different footprints for the same part. We learnt the hard way.

<figure><figcaption><p>Footprint pinout mapping. 1 bottom right, 2 top right.</p></figcaption></figure>

You'll notice our connector has far many more pins than the STM32 has outputs, we've chosen this due to stock availability, as well as we'll be able to use this same connector on future projects on STMs with higher pin counts.

| Pin Number | AP\_Periph function | STM/Physical |
| --- | --- | --- |
| 1 | | GND |
| 2 | | <mark style="background-color:red;">GND</mark> |
| 6 | | +3.3V |
| 7 | | CAN\_H |
| 9 | | CAN\_L |
| 15 | | +5V |
| 16 | | +5V |
| 32 | | PB12 |
| 33 | <mark style="color:blue;">USART3\_RX</mark> | PB11 |
| 34 | <mark style="color:purple;">SCL</mark> | PB13 |
| 35 | <mark style="color:blue;">USART3\_TX</mark> | PB10 |
| 36 | <mark style="color:purple;">SDA</mark> | PB14 |
| 37 | <mark style="color:orange;">SPI1\_CS2</mark>  | PB2 |
| 38 | | PB15 |
| 39 | | PB1 |
| 40 | | PA8 |
| 41 | | PB0 |
| 42 | | PA9 |
| 43 | <mark style="color:orange;">SPI1\_MOSI</mark> | PA7 |
| 44 | | PA10 |
| 45 | | PA6 |
| 46 | | PA11 |
| 47 | <mark style="color:orange;">SPI\_SCK</mark> | PA5 |
| 48 | | PA11 |
| 49 | <mark style="color:orange;">SPI\_CS1</mark> | PA4 |
| 50 | <mark style="color:red;">SWD</mark> | PA13 |
| 51 | <mark style="color:blue;">USART2\_RX</mark> | PA3 |
| 53 | <mark style="color:blue;">USART2\_TX</mark> | PA2 |
| 55 | | PA1 |
| 57 | | PA0 |
| 59 | | NRST |
| 66 | <mark style="color:red;">SWC</mark> | PA14 |
| 68 | | PA15 |
| 70 | <mark style="color:orange;">SPI1\_MISO</mark> | PB4 |
| 72 | | PB5 |
| 74 | <mark style="color:blue;">USART1\_TX</mark> | PB6 |
| 76 | <mark style="color:blue;">USART1\_RX</mark> | PB7 |
| 78 | | BOOT0 |
| 79 | | GND |
| 80 | | PC13 |

## Standoffs

The design requires 4x M1.6, 1.5mm standoffs. An example of these is the 9774015633R from Wurth Electronik.

{% embed url="https://www.mouser.co.uk/ProductDetail/Wurth-Elektronik/9774015633R?qs=2WXlatMagcGvxYPtvinz1A%3D%3D" %}

{% hint style="info" %}
The equivalent JLCPCB component is C2928168
{% endhint %}

## Connector position drawing

This drawing is for the hole and connector positions for the **carrier board,** not the node itself.

<div align="left"><figure><figcaption><p>Layout with Dimensions</p></figcaption></figure> <figure><figcaption><p>Example layout on Node Development Board V1.0</p></figcaption></figure></div>

## Template

A Kicad template file with required libraries can be used as a starting point to make a custom carrier board.

<figure><figcaption></figcaption></figure>

{% file src="../.gitbook/assets/micro-node-carrier-template-rev-a.zip" %}

## Software

**Arduino DroneCAN**

We wrote an Arduino library for using DroneCAN on this Node out of the box!

You can integrate your sensor how you like with minimal code. Includes bootloader support so your apps can be updated over CAN.

{% content-ref url="arduino-dronecan/" %}
[arduino-dronecan](arduino-dronecan/)
{% endcontent-ref %}

**AP\_Periph**

We support AP\_Periph based firmware's for our CAN node. The Nodes ship with a generic AP\_periph firmware by default.

{% content-ref url="ap-periph.md" %}
[ap-periph.md](ap-periph.md)
{% endcontent-ref %}

### Custom Firmware

We can flash a custom/specific firmware for your order on your request. Contact us for custom firmware to be written at _**admin@beyondrobotix.com**_

We have experience integrating virtually every type of sensor into communicating with Ardupilot or PX4, for example fuel flow sensors, ultrasound sensors, GNSS receivers, magnetometers, pressure transducers,  power monitors and many more. It is also possible to adapt the output of the Micro Node to send PWM, GPIO, CAN, Serial, I2C and SPI.

## Environmental

Based on environmental ratings for the components and board manufacturer statements. Not a tested figure by Beyond Robotix.

The boards can be conformally coated on request. If environmental considerations are a requirement for your project, contact us at _**admin@beyondrobotix.com**_ for further insight and options.

* Temperature > -20 °C to 85 °C ambient temperature

## QA Testing

We test every board we dispatch. Our process is:

* Mount the node to a test carrier
* Upload testing firmware
* Our software checks every pin is functioning as expected
* Upload customer firmware
* Check node status can be seen through CAN interface (if applicable)
* Package for dispatch

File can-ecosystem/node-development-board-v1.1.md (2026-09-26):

---
description: Pin out everything on the Micro CAN Node!
icon: square-code
---

# Node Development Board V1.1

<figure><figcaption></figcaption></figure>

This is a carrier board for the Micro CAN node.&#x20;

* The Dev carrier board is a great way of getting started using a CAN node, giving access to all the interfaces available on the node.&#x20;
* It allows easy programming of the node for custom applications, providing compatibility with debugging hardware.&#x20;
* It is also a great sensor ingestion interface for use in flight if you require lots of flexibility in development or for low unit numbers.&#x20;
* For production platforms, this board will give you the opportunity to test ideas quickly and hone in on a production carrier board design to use with the Micro CAN node.&#x20;

## Store

{% embed url="https://www.beyondrobotix.com/products/micro-can-node-development-bundle" %}

## Mechanical

The CAD file for the node development carrier can be found below, along with the outer and mounting dimensions of the carrier.

The holes on the carrier board are M3.

{% file src="../.gitbook/assets/node-development-board-v1.1.step" %}

<figure><figcaption></figcaption></figure>

## Available interfaces

The Dev board interfaces follow Pixhawk pin out standards or RC common convention where applicable. Please double check the interface pin outs for your application. We've included a lot of information on the back of the board which should help with most questions.

<figure><figcaption></figcaption></figure>

### CAN

The Micro Node has 1 available CAN interface, which is pinned out to 2 JST-GH CAN ports, to allow CAN device chaining.&#x20;

| Pin Number | Description |
| --- | --- |
| 1 | Vcc (5V) |
| 2 | CANH |
| 3 | CANL |
| 4 | GND |

### I2C

The Micro Node has 1 available I2C interface,  which has been pinned out to a single JST-GH port. This has selectable 3.3V out or 5V out depending on how JP2 is set. By default, JP2 is set to 5V out.

<figure><figcaption><p>Swapping 5V to 3.3V</p></figcaption></figure>

To set to 3.3V out:

* Cut the trace between pad 1 and 2 on JP2
* Check there is now no continuity between pad 1 and 2
* Create a solder bridge between pad 2 and 3

{% hint style="info" %}
The Node Development Board also has 4.7K Ohm pull ups for SCL and SDA. These can be removed by cutting JP1&#x20;
{% endhint %}

| Pin | Description |
| --- | --- |
| 1 | Vcc (5V or 3.3V) |
| 2 | SCL |
| 3 | SDA |
| 4 | GND |

### Serial

The Micro Node has 3 serial interfaces available. Serial 1 and 3 are pinned out to JST-GH connectors. Serial 2 is used for the USB or ST-Link interfaces on the Node Development Board.&#x20;

#### Serial 1 and Serial 3

| Pin | Description |
| --- | --- |
| 1 | Vcc (5V) |
| 2 | UARTx\_TX |
| 3 | UARTx\_RX |
| 4 | N/C |
| 5 | N/C |
| 6 | GND |

#### Serial 2

This is the program upload/console port for the Micro Node. See the STLINK header section for the pinout.

### GPIO/PWM

The dev node has lots of GPIOs and PWMs available. These are denoted by a "\~" on the board pin.

PWMs:

* PA0
* PA1
* PA8
* PA10
* PA11
* PB15
* PA15

{% hint style="info" %}
When using Arduino DroneCAN, these pins can be accessed in your program using `PA_8` in your code for PA8
{% endhint %}

Any logical pin can be used as a GPIO.

### ADC

The Dev node has 8 ADCs pinned out, denoted by a \* by the board pin.

* PA0
* PA1
* PB0
* PA6
* PA4
* PB1
* PA7
* PA5

These pins can be read in ArduinoDroneCAN like:

```cpp
analogRead(PA0);
```

{% hint style="danger" %}
The maximum voltage of the ADC pins is 3.3V.
{% endhint %}

## Programming the board

There are a few ways of interfacing with the development board, depending on what you're trying to achieve!

### ST-LINK

{% hint style="success" %}
This is the recommended method for programming the Micro Node. It has many useful features to help debugging and makes programming easy.
{% endhint %}

STM32 allows the ability to easily debug programs over SWDIO. This allows live variable inspection, breakpoints and more - which makes program development much easier!

{% hint style="info" %}
To use the STLINK header, the switch SW1 needs to be set to 1 to disable the onboard USB to serial
{% endhint %}

The "STLINKV3" header is directly compatible with the [STLINK-V3MINIE](https://www.st.com/en/development-tools/stlink-v3minie.html). To upload code to the Micro node, simply:

1. Connect the node to the STLINKV3
2. Click upload or debug in VS-Code!

The pins on the ST-LINK header could also be used with normal Arduino jumpers so a STLINKV2, or another SWD based debugger could be used. The pins are as follows:

<figure><figcaption><p>STLINK Header</p></figcaption></figure>

<table><thead><tr><th width="246">Pin Number</th><th>Description</th></tr></thead><tbody><tr><td>1</td><td><mark style="color:orange;">NC</mark></td></tr><tr><td>2</td><td><mark style="color:orange;">NC</mark></td></tr><tr><td>3</td><td>5V in</td></tr><tr><td>4</td><td>SWD</td></tr><tr><td>5</td><td><mark style="color:blue;">GND</mark></td></tr><tr><td>6</td><td>SWC</td></tr><tr><td>7</td><td><mark style="color:blue;">GND</mark></td></tr><tr><td>8</td><td><mark style="color:orange;">NC</mark></td></tr><tr><td>9</td><td><mark style="color:orange;">NC</mark></td></tr><tr><td>10</td><td><mark style="color:blue;">GND</mark></td></tr><tr><td>11</td><td><mark style="color:orange;">NC</mark></td></tr><tr><td>12</td><td><mark style="color:orange;">NC</mark></td></tr><tr><td>13</td><td>UART2_TX</td></tr><tr><td>14</td><td>UART2_RX</td></tr></tbody></table>

### Using the USB connection

The dev board comes with a USB C connection and has a built in USB to UART converter to be able to communicate with our CAN node. This can be used to program the CAN node over serial. The CAN node needs to be in boot loader mode to do this.&#x20;

{% hint style="info" %}
To use the onboard USB connection, the USB switch needs to be set to ON
{% endhint %}

To put the CAN node into boot loader mode:

1. Hold down the boot loader button
2. press the reset button

Once in boot loader mode, you can use&#x20;

1. STM cube programmer to upload AP\_Periph firmware over serial [https://www.st.com/en/development-tools/stm32cubeprog.html](https://www.st.com/en/development-tools/stm32cubeprog.html)
2. PlatformIO for Arduino DroneCAN projects. Currently serial upload isn't working in PlatformIO, the generated .Bin file needs to be uploaded through STM32CubeProgrammer selecting "serial" connection method.
3. Other tool chains!

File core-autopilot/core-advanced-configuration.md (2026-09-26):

---
icon: gear
---

# Advanced Configuration

## Power monitoring

Four current sense channels are available for ArduPilot battery monitor instances:

| ArduPilot instance | MCU pin | Sense point | hwdef name |
| --- | --- | --- | --- |
| BATT5 | PC3 (ADC1)  | PWR1 input current | `BATT5_CURRENT_SENS` |
| BATT6 | PF11 (ADC1) | PWR2 input current | `BATT6_CURRENT_SENS` |
| BATT7 | PA6 (ADC1)  | USB power layer current | `BATT7_CURRENT_SENS` |
| BATT8 | PF13 (ADC2) | USB carrier current | `BATT8_CURRENT_SENS` |

These measure current only. The board does not have direct access to raw battery voltage — voltage monitoring should be done externally via a DroneCAN power module, or via a resistor divider on ADC7 or ADC8 (J2 pins 67 and 57).

A 5 V bus sense line (`VDD_5V_SENS` on PF3, ADC3) monitors the internal 5 V rail through a 1:1 divider and is configured with `SCALE(2)`.

***

## PWM voltage selection

PWM outputs 1–8 (MAIN) pass through level-shifting buffers whose output voltage is software-selectable between 3.3 V and 5 V. The default in the firmware is **3.3 V**.

To switch to 5 V output (required for most standard RC servos):

```
SERVO_BLH_POLES = 0    # not related, just context
# Set GPIO 3 HIGH for 5V, LOW for 3.3V
```

In ArduPilot, control this via the `HAL_GPIO_PWM_VOLT_PIN` (GPIO 3, PI6):

```python
# From GCS or scripting:
param set BRD_PWM_VOLT_EN 1     # if available in your build
```

Or directly via the `relay` interface:

```
RELAY1_PIN = 3        # GPIO 3 = PWM voltage selector
RELAY1_DEFAULT = 1    # 1 = HIGH = 5V output
```

Then use `do-set-relay` in a mission or MAVLink command to toggle. Set to HIGH (1) for 5 V servo output, LOW (0) for 3.3 V.

> PWM outputs 9–18 (AUX) are direct GPIO outputs and are always 3.3 V regardless of this setting.

***

## Relay / GPIO outputs

Two additional high-current enable outputs control the 5V power rails and can also be used as relays if power switching is needed:

| Function | MCU pin | GPIO number | Default |
| --- | --- | --- | --- |
| HI\_PWR\_EN (Telem 5V) | PJ0 | 85 | HIGH (on) |
| PERIPH\_PWR\_EN (Peripherals 5V) | PJ1 | 86 | HIGH (on) |

> **Caution:** disabling PERIPH\_PWR\_EN (GPIO 86) will cut power to all peripherals on the Peripherals 5V rail. Only use this as a relay if you understand the downstream effects.

***

## Ethernet

The board includes a LAN8742A 100BASE-TX Ethernet PHY. The interface is enabled automatically at boot with no configuration required.

To use MAVLink 2 over UDP:

```
SERIAL2_PROTOCOL = 2      # or any free serial
# Then configure network via:
NET_ENABLE = 1
NET_IPADDR0..3 = 192.168.1.2   # static IP
NET_GWADDR0..3 = 192.168.1.1
NET_NETMASK0..3 = 255.255.255.0
NET_P1_TYPE = 1           # UDP client
NET_P1_IP0..3 = 192.168.1.100  # GCS IP
NET_P1_PORT = 14550
```

Typical use cases include a companion computer (Raspberry Pi, NVIDIA Orin) running ROS 2 / MAVROS connected via Ethernet for high-bandwidth telemetry and onboard processing.

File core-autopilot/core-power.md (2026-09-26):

# Core Power

{% hint style="info" %}
This page is under construction. Please contact admin@beyondrobotix.com for further information.
{% endhint %}

This page will contain detailed power information for the core autopilot.

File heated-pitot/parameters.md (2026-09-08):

---
icon: wrench
---

# Parameters

| Parameter | Type | Default | Min | Max  | Units |
| --- | ---- | --- | --- | ---- | --- |
| `NODEID` | INT  | 100 | 1 | 127  | — |
| `DEVICE_ID` | INT  | 0 | 0 | 127  | — |
| `T_THRESHOLD` | INT  | 10 | 0 | 40 | °C |
| `EN_FAIRWEATHER` | BOOL | 0 | 0 | 1 | — |
| `P_MAX` | INT  | 70 | 0 | 70 | W |
| `CMD_CHANNEL` | INT  | 10 | 0 | 100  | — |
| `T_TARGET` | INT  | 60 | 40  | 80 | °C |
| `ASP_GATE` | INT  | 15 | 0 | 100  | m/s |
| `FAULT_S` | INT  | 60 | 10  | 600  | s |
| `TELEM_EN` | BOOL | 1 | 0 | 1 | — |
| `R_HEATER` | INT  | 235 | 50  | 1000 | ×0.01 Ω  |
| `SELFTEST` | BOOL | 0 | 0 | 1 | — |

***

## Node / bus identity

#### `NODEID`

The DroneCAN node ID this device claims on the bus by default. Will respect DNA allocation from the autopilot if this ID is already taken. **Changing this only takes effect after the node is restarted.**

* Default: `100` · Range: `1`–`127`

#### `DEVICE_ID`

Battery / device identifier reported in the published `BatteryInfo.battery_id` field. Use it to tell multiple heated-pitot nodes apart in the autopilot's battery monitor / logs. Has no effect on control behaviour.

* Default: `0` · Range: `0`–`127`

***

## Command interface

#### `CMD_CHANNEL`

The actuator channel (`actuator_id`) this node listens to in an `uavcan.equipment.actuator.ArrayCommand`. The autopilot uses this channel to turn the heater **on** or **off**:

* **PWM command type:** value `< 500` is ignored (no change); `≥ 1500` = ON (arm), otherwise OFF.
* **Unitless command type:** value must be within `-1…1`; `≥ 0.75` = ON, `≤ 0.25` = OFF, in-between = no change.

If no actuator command is received for 5 s while the heater is OFF, the node fails **safe to ON** (re-initialises the heater) so a lost link doesn't leave the pitot unheated.

* Default: `10` · Range: `0`–`100`

***

## Temperature control

#### `T_TARGET`

The heater temperature setpoint the PID loop drives toward, in °C. This is the regulated operating temperature of the probe.

We currently recommend at least 60 degrees to ensure ice is melted quickly from the probe, however, with further testing Beyond Robotix may be able to recommend a reduced temperature to save power.

* Default: `60` °C · Range: `40`–`80` °C

#### `T_THRESHOLD`

Fair-weather activation threshold, in °C. While `EN_FAIRWEATHER` is enabled, the heater stays idle until the measured temperature drops **below** this value (or fair-weather is disabled), at which point it moves into active heating.

* Default: `10` °C · Range: `0`–`40` °C

#### `EN_FAIRWEATHER`

Enables fair-weather idling. When `1`, the heater sits idle (in `FAIR_WEATHER`) until it's cold enough (see `T_THRESHOLD`) to be worth heating, saving power in warm conditions. When `0`, the heater skips fair-weather and always progresses to active temperature regulation.

* Default: `0` (disabled) · Range: `0`–`1`

***

## Power / regulator limits

#### `P_MAX`

Maximum heater power, in watts. This caps the upper limit of the PID output and therefore the most power the regulator will deliver to the heating element.

* Default: `70` W · Range: `0`–`70` W

> **Note:** input voltage below \~12 V reduces the regulator's achievable maximum output regardless of this setting; the node emits a `Vin < 12V` warning when that happens.

***

## Fault detection
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

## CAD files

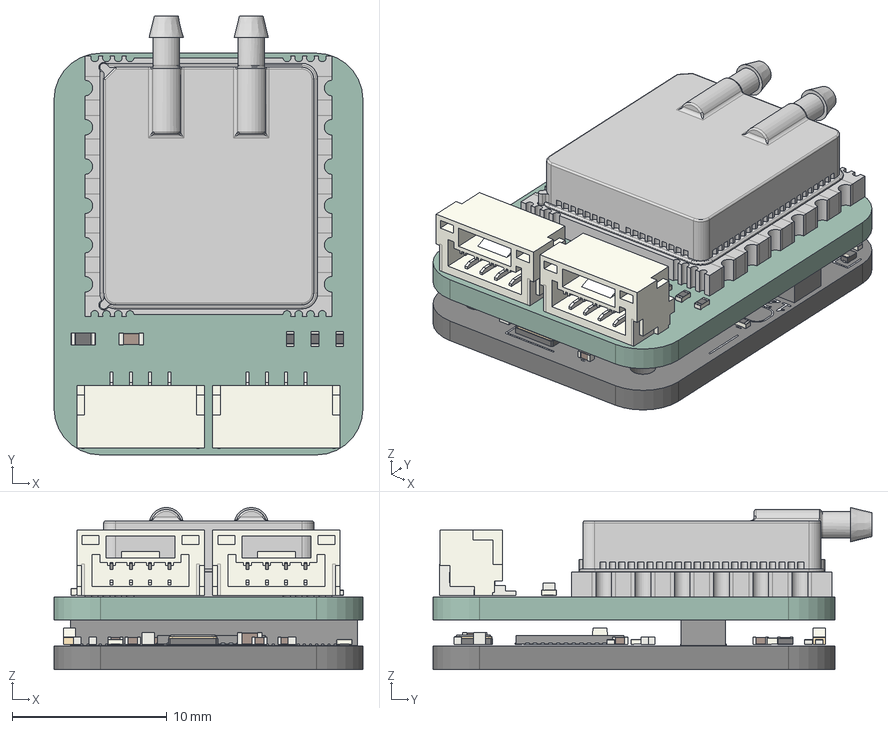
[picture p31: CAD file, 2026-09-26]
.gitbook/assets/air-data-module-pcb.step
20.0 x 28.4 x 10.6 mm
JST_GH_SM04B-GHS-TB_1x04-1MP_P1.25mm_Horizontal x 2
R_0402_1005Metric x 3
R_0603_1608Metric
C_0603_1608Metric
Pins
PCB AS01-08-078A
AS01-01-060 Rev A1
Adhesive
C_0603_1608Metric_1 x 2
ThermalPin
PinsArrayLR
PinsArrayTB
C_0402_1005Metric x 10
LED_0603_1608Metric x 2
R_0402_1005Metric_1 x 4
Crystal_SMD_3225-4Pin_3.2x2.5mm
R_0603_1608Metric_1
Fuse_0402_1005Metric
D_SOD-882D
DF40C-80DP-0.4V_51_
STM32L4 CAN Node_silkscreen
STM32L4 CAN Node_PCB

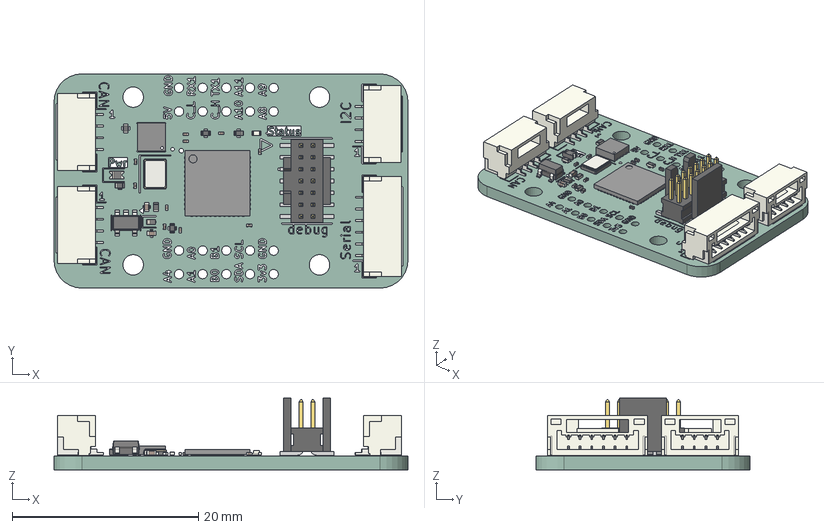
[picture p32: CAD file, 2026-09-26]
.gitbook/assets/can-node-v1.0.step
38.0 x 23.0 x 7.79 mm
JST_GH_SM04B-GHS-TB_1x04-1MP_P1.25mm_Horizontal x 3
C_0201_0603Metric x 10
FTSH-107-01-L-DV-K_body
FTSH-107-01-L-DV-K_pins1
FTSH-107-01-L-DV-K_pins2
LED_0402_1005Metric
R_0402_1005Metric x 5
ThermalPin
PinsArrayLR
PinsArrayTB
C_0402_1005Metric x 2
JST_GH_SM06B-GHS-TB_1x06-1MP_P1.25mm_Horizontal
SOT-23-5
D_0603_1608Metric
TJA1051TK_3_1J
D_SOD-882D
Fuse_0402_1005Metric
Crystal_SMD_3225-4Pin_3.2x2.5mm
STM32L4 Plain Node_silkscreen
STM32L4 Plain Node_PCB

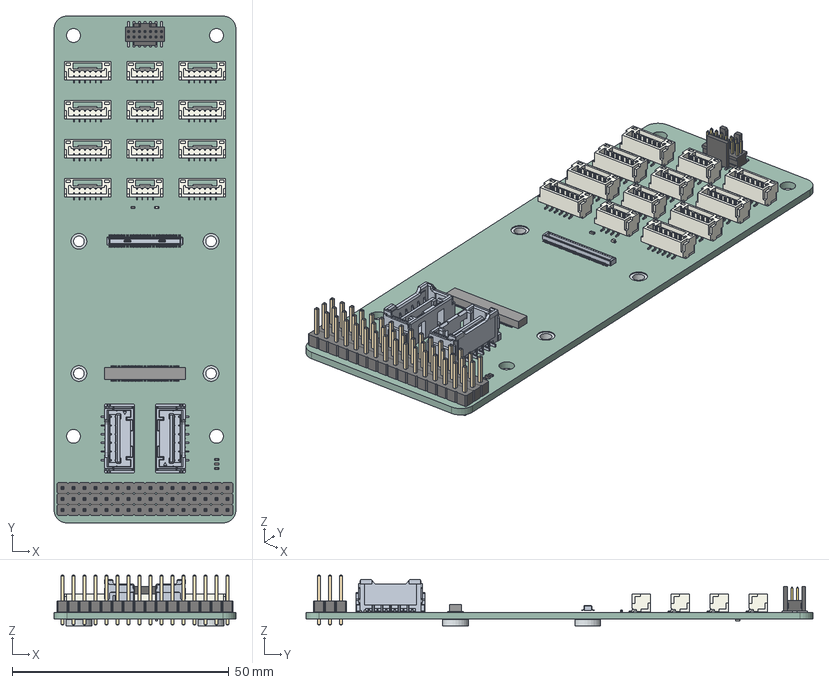
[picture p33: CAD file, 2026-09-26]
.gitbook/assets/connector-layer-default.step
42.0 x 117.0 x 11.7 mm
JST_GH_BM06B-GHS-TBT_1x06-1MP_P1.25mm_Vertical x 8
R_0402_1005Metric x 5
C_0402_1005Metric
PinHeader_1x16_P2.54mm_Vertical x 3
DF40C-80DP-0.4V_51_
FTSH-107-01-L-DV-K_body
FTSH-107-01-L-DV-K_pins1
FTSH-107-01-L-DV-K_pins2
LED_0402_1005Metric
JST_GH_BM04B-GHS-TBT_1x04-1MP_P1.25mm_Vertical x 4
Pins x 2
connector_layer_default_PCB

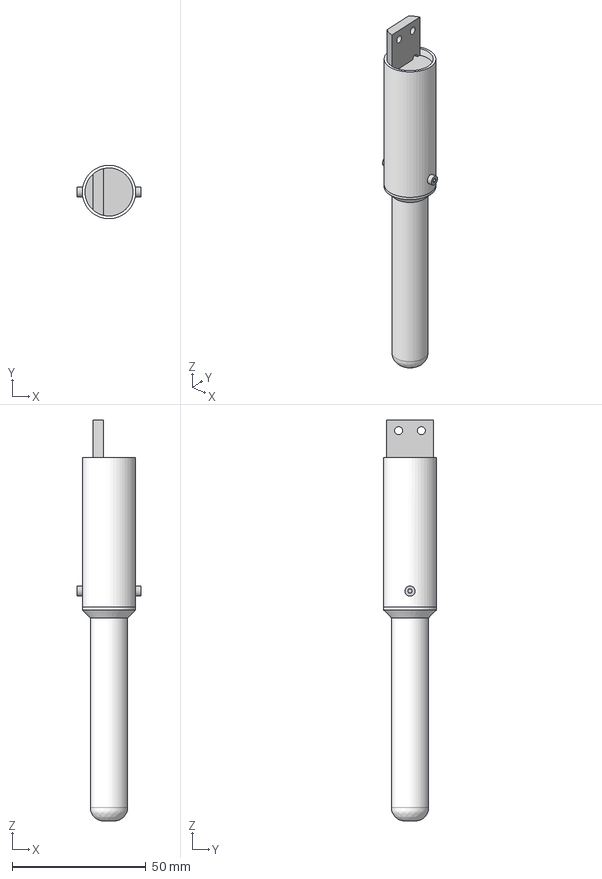
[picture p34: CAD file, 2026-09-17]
.gitbook/assets/Beyond Robotix Heated Pitot Space Model.step
24.0 x 20.0 x 150.0 mm
heated pitot tip space saver

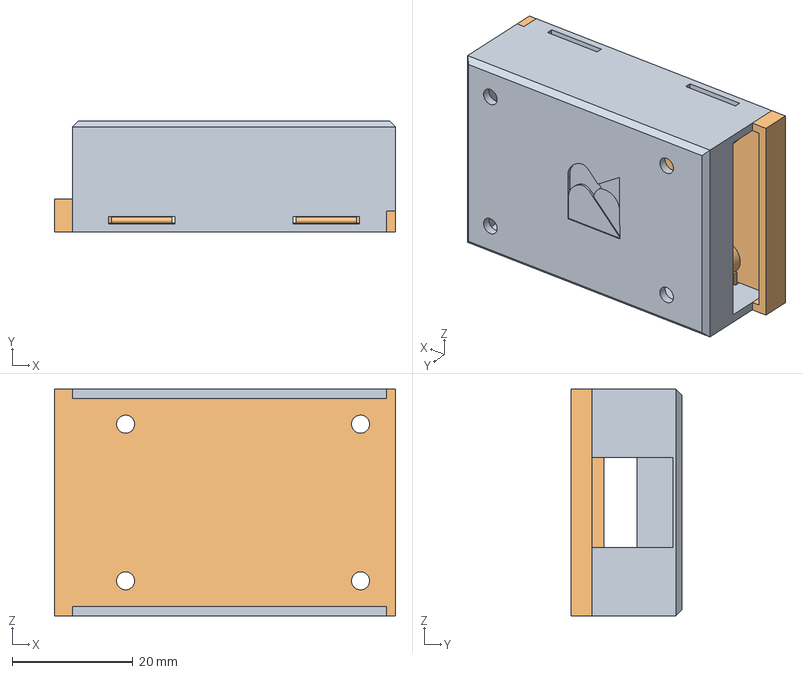
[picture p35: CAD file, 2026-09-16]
.gitbook/assets/Heated Pitot Control Module.step
56.6 x 18.5 x 37.6 mm

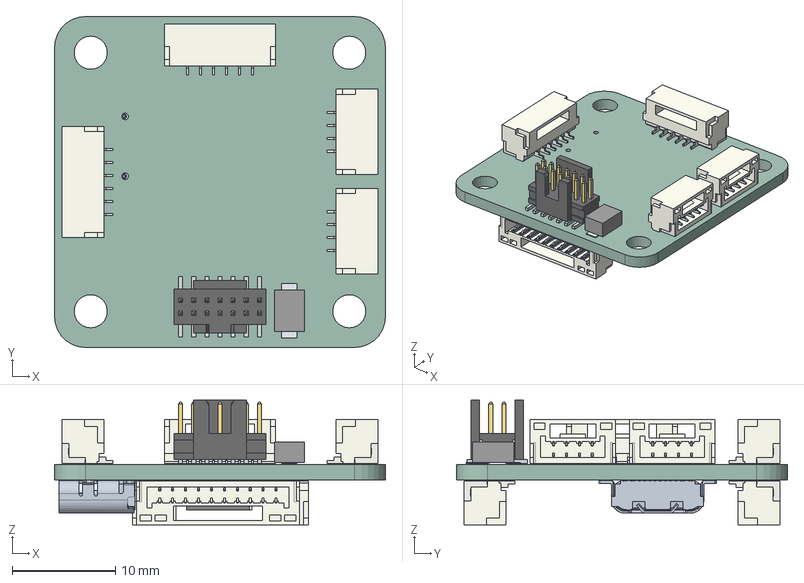
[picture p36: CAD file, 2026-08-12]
.gitbook/assets/can-node-plus.step
32.0 x 32.0 x 12.0 mm
JST_GH_SM04B-GHS-TB_1x04-1MP_P1.25mm_Horizontal x 2
FTSH-107-01-L-DV-K_body
FTSH-107-01-L-DV-K_pins1
FTSH-107-01-L-DV-K_pins2
JST_GH_SM06B-GHS-TB_1x06-1MP_P1.25mm_Horizontal x 2
Pins
JST_GH_SM10B-GHS-TB_1x10-1MP_P1.25mm_Horizontal
JST_GH_SM11B-GHS-TB_1x11-1MP_P1.25mm_Horizontal
GSB1C41110SSHR
Micro Node Plus Attempt 2_PCB

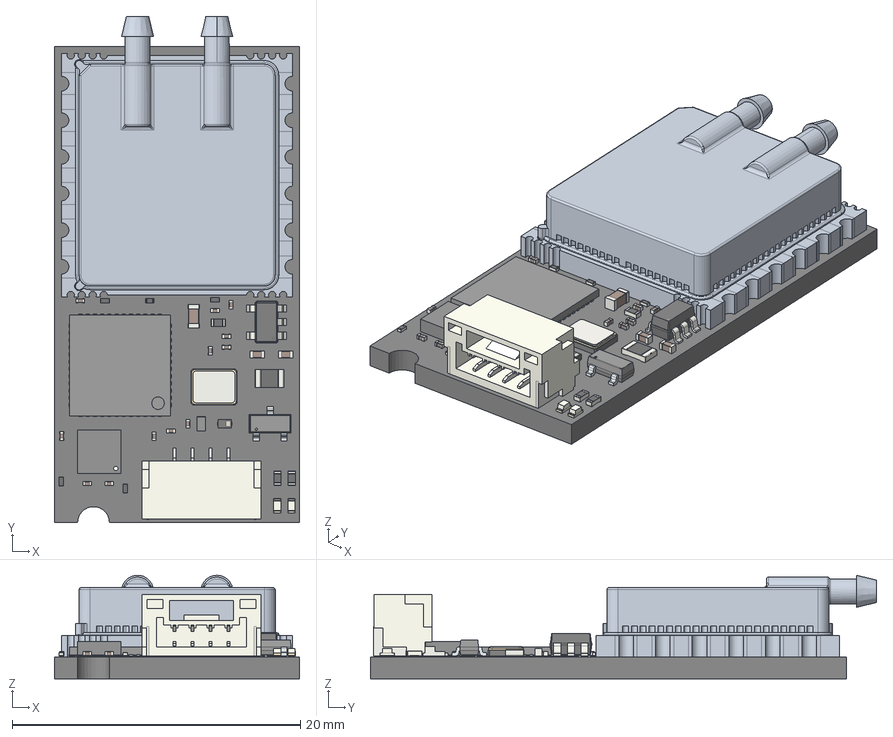
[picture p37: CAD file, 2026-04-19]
.gitbook/assets/air-data-module-mini.step
17.0 x 35.1 x 7.19 mm
SOT-23-5
C_0201_0603Metric x 12
R_0201_0603Metric x 5
pins
JST_GH_SM04B-GHS-TB_1x04-1MP_P1.25mm_Horizontal
LED_0402_1005Metric x 2
ThermalPin
PinsArrayLR
PinsArrayTB
C_0402_1005Metric x 2
R_0402_1005Metric x 3
D_SOD-882D
PinsArrayL
FilletPinR
TJA1051TK_3_1J
C_0603_1608Metric
Crystal_SMD_3225-4Pin_3.2x2.5mm
PCB AS01-08-078A
AS01-01-060 Rev A1
Adhesive
Fuse_0805_2012Metric
AUAV ADM_PCB

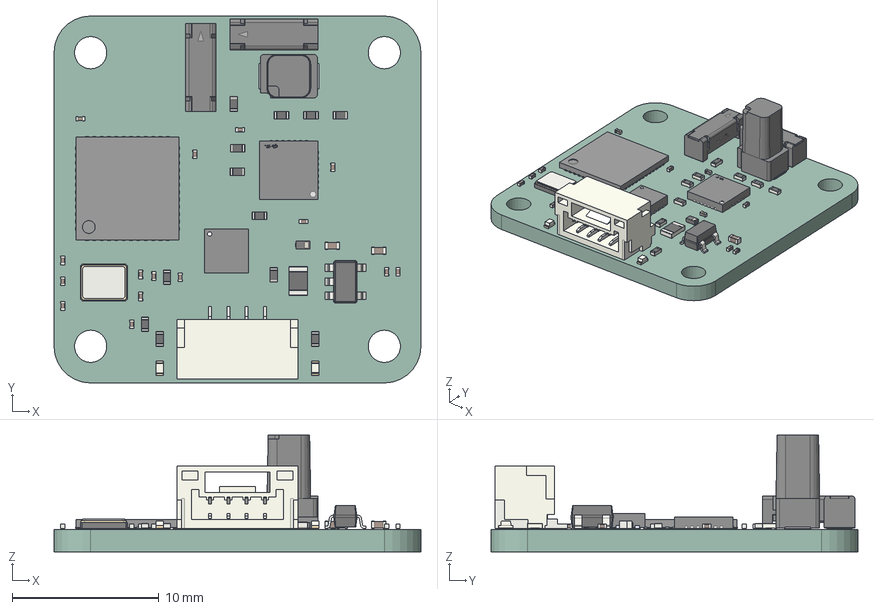
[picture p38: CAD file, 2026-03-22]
.gitbook/assets/rm3100-compass.step
25.0 x 25.0 x 7.94 mm
R_0402_1005Metric x 12
SOT-23-5
C_0201_0603Metric x 15
RM3100_XY x 2
JST_GH_SM04B-GHS-TB_1x04-1MP_P1.25mm_Horizontal
LED_0402_1005Metric x 2
ThermalPin
PinsArrayLR
PinsArrayTB
C_0402_1005Metric x 2
D_SOD-882D
RM3100_Z
TJA1051TK_3_1J
Crystal_SMD_3225-4Pin_3.2x2.5mm
PNI13156
Fuse_0805_2012Metric
Mag Node RM3100_PCB

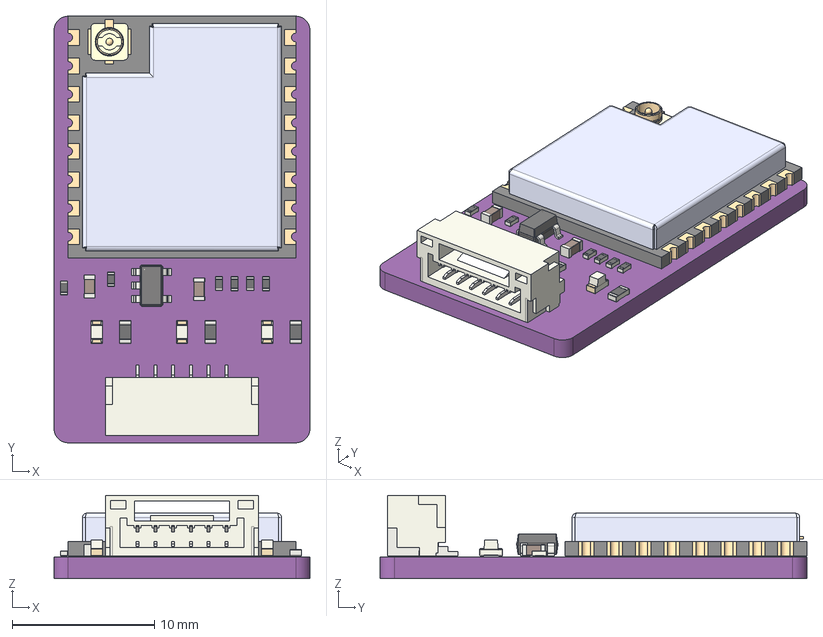
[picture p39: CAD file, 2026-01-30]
.gitbook/assets/kahuna-v1.2.step
18.0 x 30.0 x 5.84 mm
R_0402_1005Metric x 6
R_0603_1608Metric x 3
LED_0603_1608Metric x 3
JST_GH_SM06B-GHS-TB_1x06-1MP_P1.25mm_Horizontal
C_0603_1608Metric x 2
SOT-23-5
ESP-07S_ESP-07S
Antenna Jack_Antenna Jack
KahunaV1.1_PCB

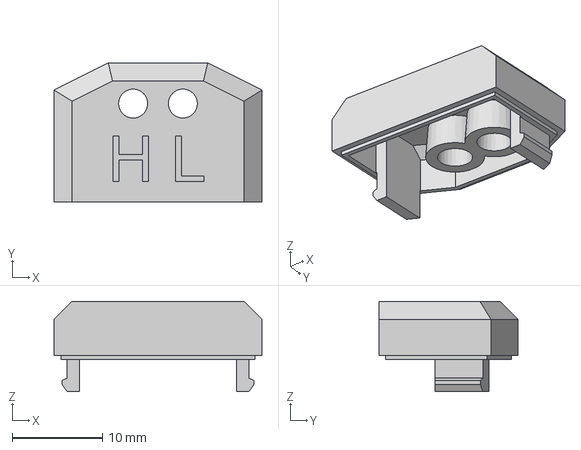
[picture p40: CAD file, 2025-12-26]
.gitbook/assets/air-data-module-case-lid.step
23.0 x 15.4 x 10.0 mm

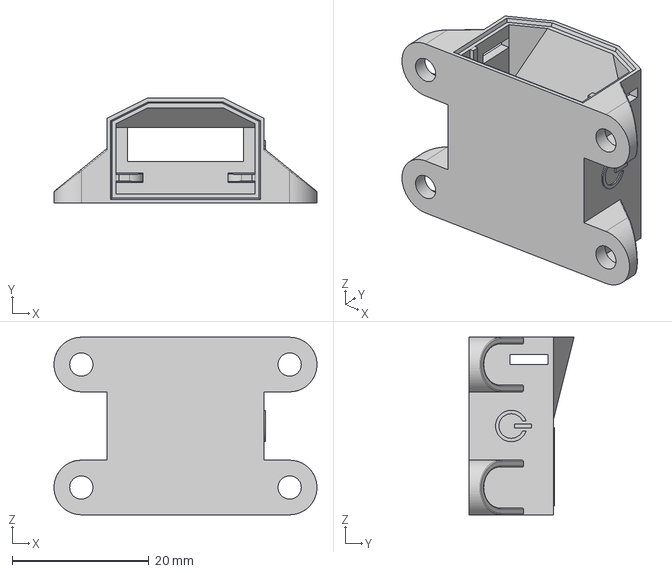
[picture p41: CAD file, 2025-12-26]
.gitbook/assets/air-data-module-case-base.step
38.5 x 15.4 x 26.0 mm

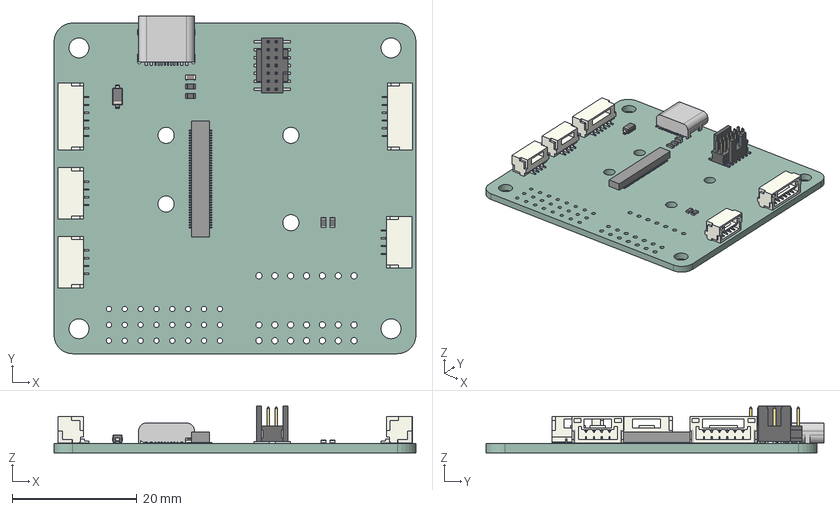
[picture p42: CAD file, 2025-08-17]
.gitbook/assets/node-development-board-v1.1.step
58.0 x 54.1 x 7.51 mm
JST_GH_SM04B-GHS-TB_1x04-1MP_P1.25mm_Horizontal x 3
HRO TYPE-C-31-M-12
R_0603_1608Metric x 4
JST_GH_SM06B-GHS-TB_1x06-1MP_P1.25mm_Horizontal x 2
D_SOD-123
C_0603_1608Metric
Pins
FTSH-107-01-L-DV-K_body
FTSH-107-01-L-DV-K_pins1
FTSH-107-01-L-DV-K_pins2
Carrier CAN Node Rev F_PCB

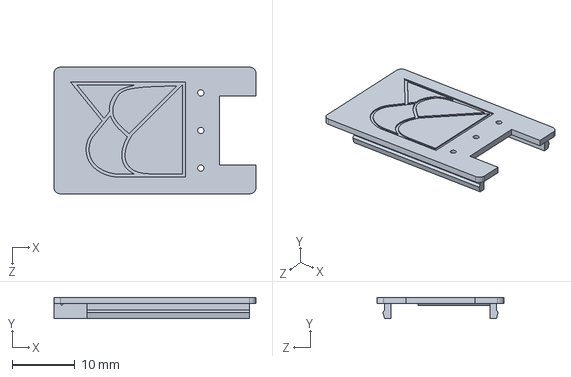
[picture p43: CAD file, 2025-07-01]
.gitbook/assets/kahuna-case-top.sldprt
32.2 x 3.40 x 20.2 mm

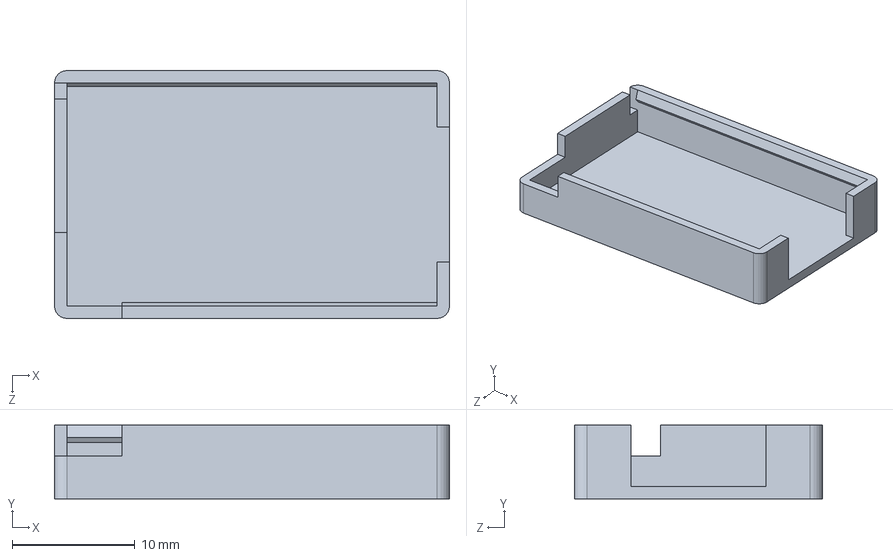
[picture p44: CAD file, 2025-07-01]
.gitbook/assets/kahuna-case-base.sldprt
32.2 x 6.00 x 20.2 mm

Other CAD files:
.gitbook/assets/node-development-board-v1.0.step
.gitbook/assets/air-data-module-case-base.3mf
.gitbook/assets/air-data-module-case-lid.3mf
.gitbook/assets/kahuna-case-base.stl
.gitbook/assets/kahuna-case-top.stl

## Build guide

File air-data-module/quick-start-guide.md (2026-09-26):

# Quick Start Guide

{% hint style="info" %}
The following also applies to the Air Data Module Mini when refereing to the AUAV sensor.
{% endhint %}

The Beyond Robotix Air Data Module includes the following:

* AUAV Sensor Board
* Micro CAN Node
* Pitot Static Tube
* Silicone tube
* Case

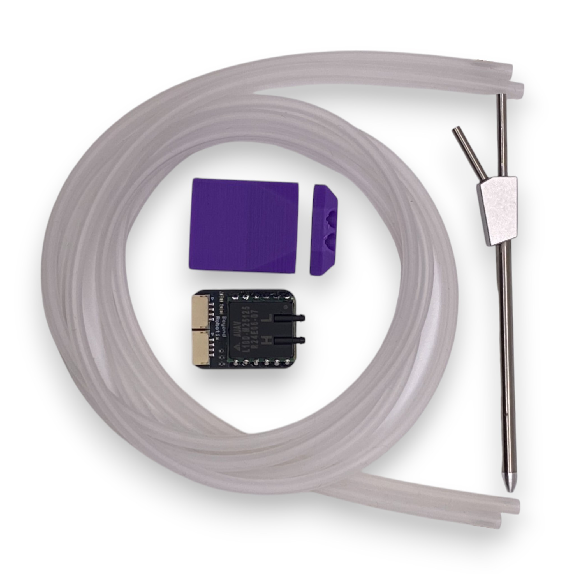
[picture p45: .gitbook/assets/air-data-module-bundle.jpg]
<figure><figcaption></figcaption></figure>

## Assembly

1. Feed the tube through the lid of the case until there is about 1 mm protruding through the lid.&#x20;

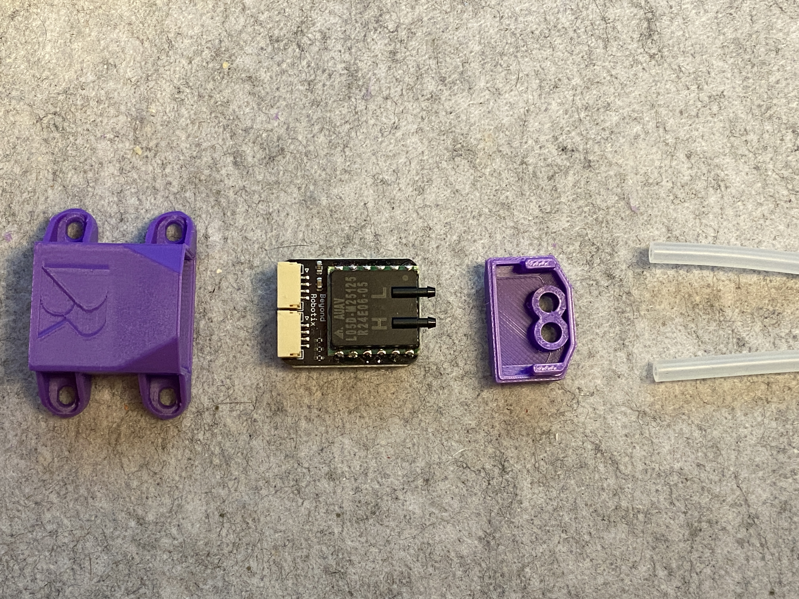
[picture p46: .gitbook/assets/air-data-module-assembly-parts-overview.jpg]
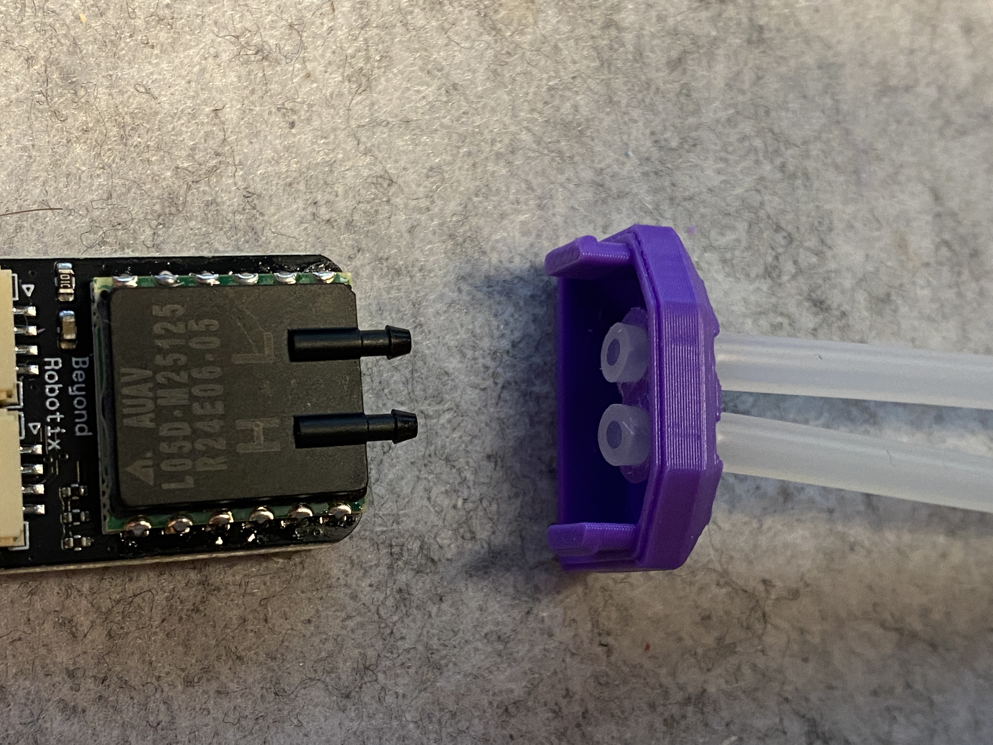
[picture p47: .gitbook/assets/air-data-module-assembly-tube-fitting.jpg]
<div><figure><figcaption></figcaption></figure> <figure><figcaption></figcaption></figure></div>

2. Insert the AUAV sensor into the tubes and pull the tubes gently until the sensor is flush with the plastic

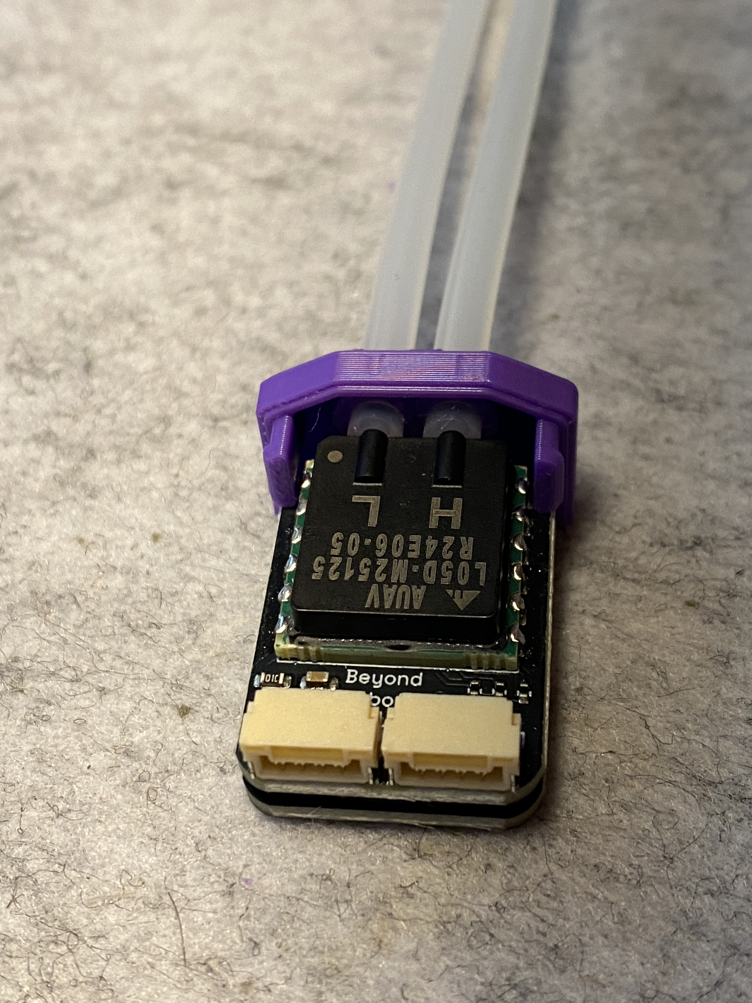
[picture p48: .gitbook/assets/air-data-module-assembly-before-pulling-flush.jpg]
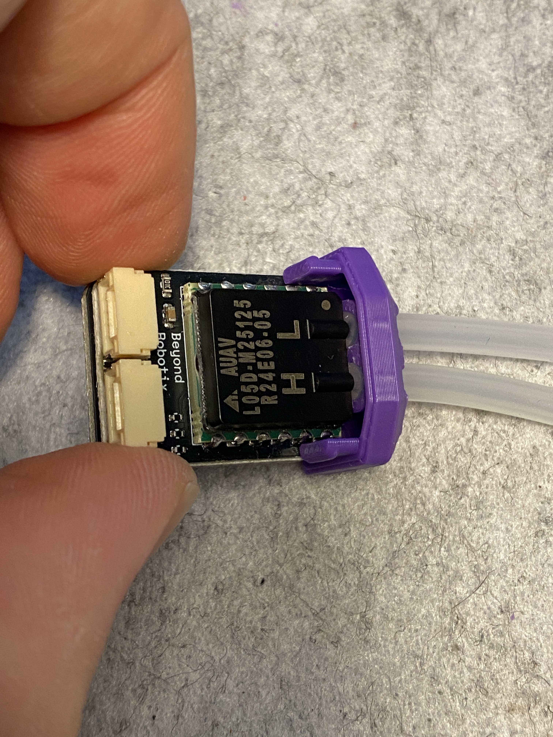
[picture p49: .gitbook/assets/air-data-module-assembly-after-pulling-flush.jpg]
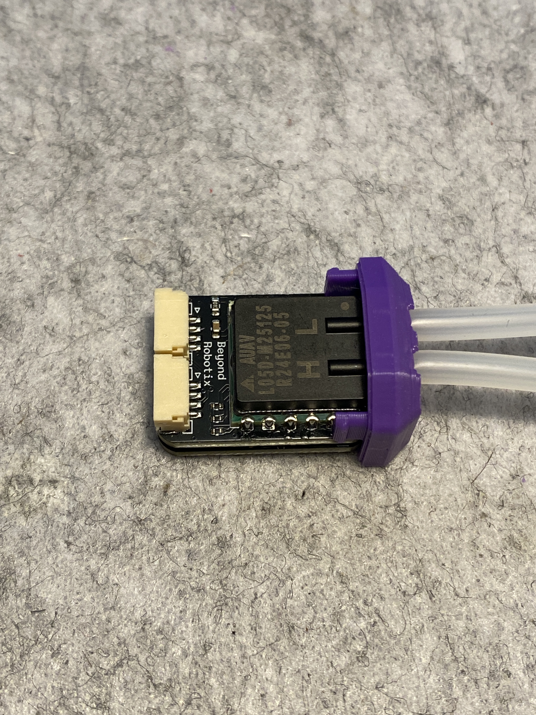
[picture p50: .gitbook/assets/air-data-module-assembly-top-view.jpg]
<div><figure><figcaption><p>Before pulling flush</p></figcaption></figure> <figure><figcaption><p>After pulling flush</p></figcaption></figure> <figure><figcaption><p>Top View</p></figcaption></figure></div>

3. Slide the sensor assembly into the main case and press until you feel a click

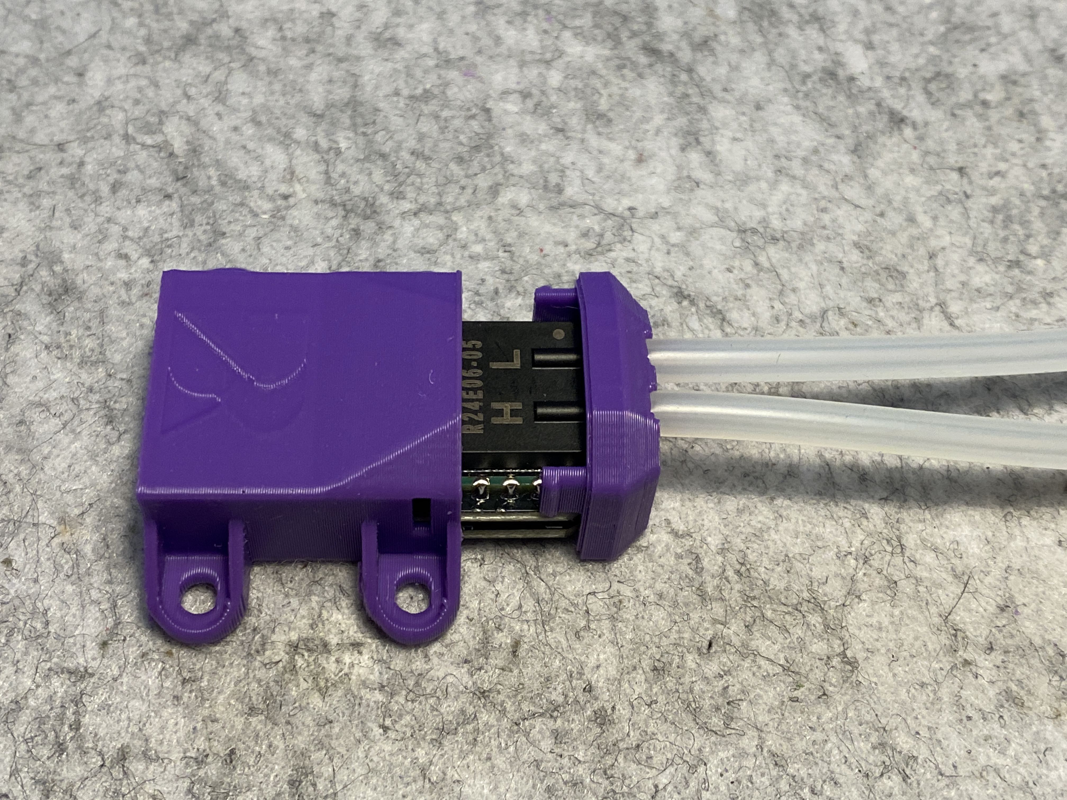
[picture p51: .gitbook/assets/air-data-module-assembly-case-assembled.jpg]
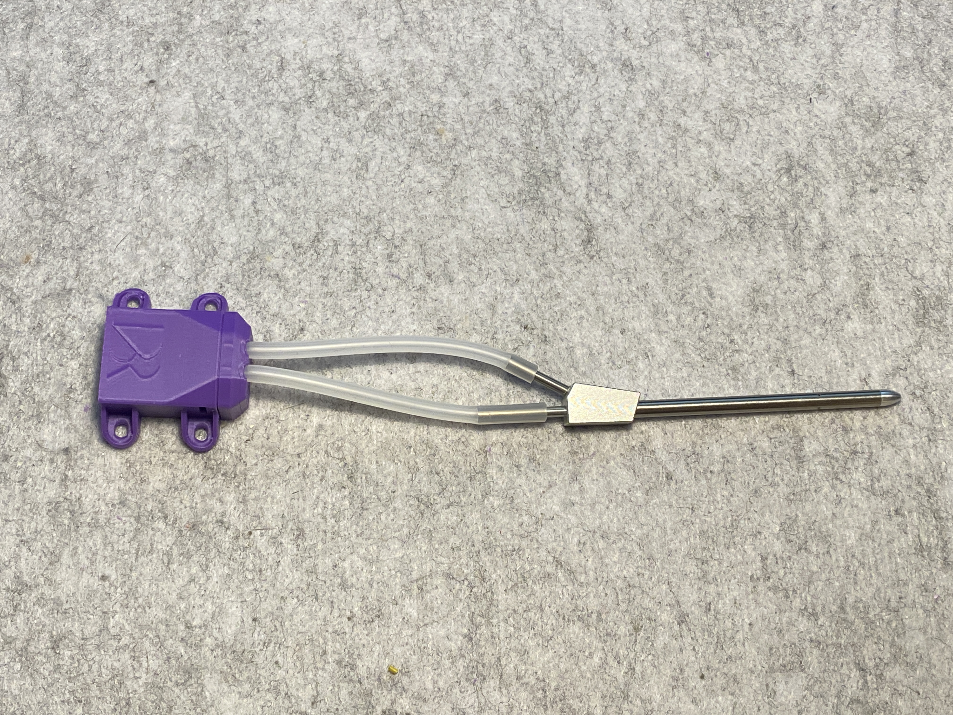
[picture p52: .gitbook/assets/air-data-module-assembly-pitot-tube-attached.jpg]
<div><figure><figcaption></figcaption></figure> <figure><figcaption></figcaption></figure></div>

4. Fix the pitot static tube to the tubes from the airspeed sensor.&#x20;

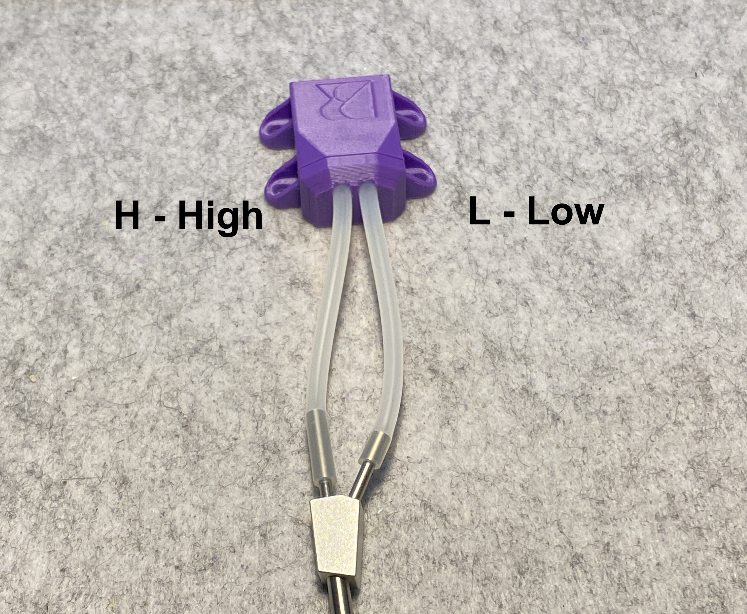
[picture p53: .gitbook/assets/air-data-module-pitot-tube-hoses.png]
<figure><figcaption></figcaption></figure>

{% hint style="success" %}
Ensure the **high** side (H) of the sensor is connected to the **straight** barb on the pitot-static tube (going to the total pressure port) and the **low** side (L) of the sensor to the **diagonal** barb (going to the static ports).
{% endhint %}

5. Connect to one of your CAN ports on your flight controller

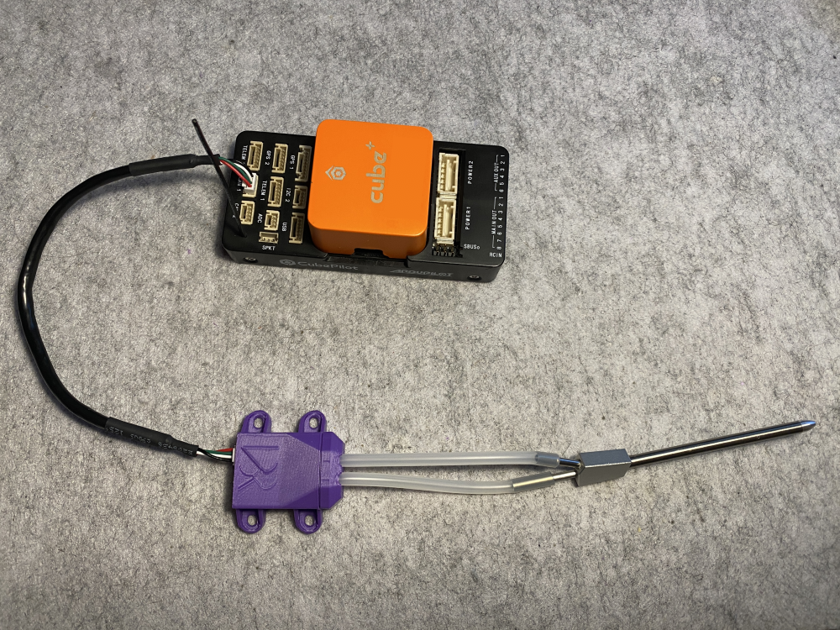
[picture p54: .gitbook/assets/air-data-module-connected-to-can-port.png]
<figure><figcaption></figcaption></figure>

5. Set the following parameters, if they are not already set:
   1. CAN\_D1\_PROTOCOL = 1 (DroneCAN)
   2. CAN\_P1\_DRIVER = 1 (First Driver)
   3. ARSPD\_ENABLE = 1 (ENABLE)
   4. ARSPD\_TYPE = 8 (DroneCAN)
6. Save parameters and reboot your autopilot. You should be able to see the airspeed and barometer sensor in the HW ID tab of Mission Planner.

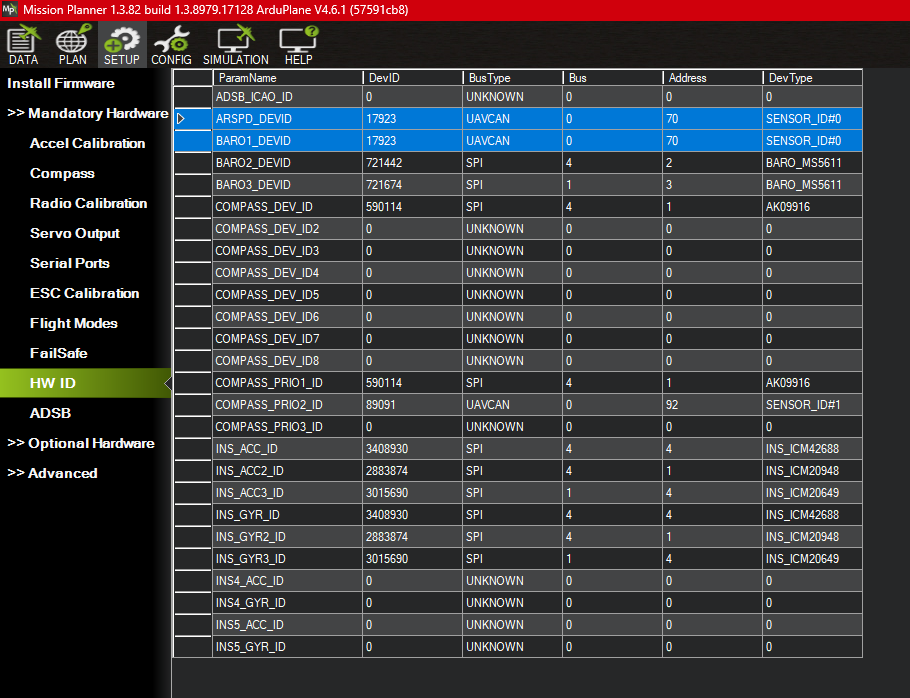
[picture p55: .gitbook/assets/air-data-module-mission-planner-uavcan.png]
<figure><figcaption><p>Airspeed and barometer show up as UAVCAN</p></figcaption></figure>

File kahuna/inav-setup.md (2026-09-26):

---
description: Get your Kahuna set up with INAV using MAVLink
icon: drone
---

# INAV Setup

INAV supports MAVLink in a limited capacity, meaning the Kahuna can be used to view telemetry on a ground station. Flight controllers running INAV can transmit telemetry over MAVLink but cannot receive commands.

#### Step 1:

Connect the Kahuna to a free UART on your autopilot.

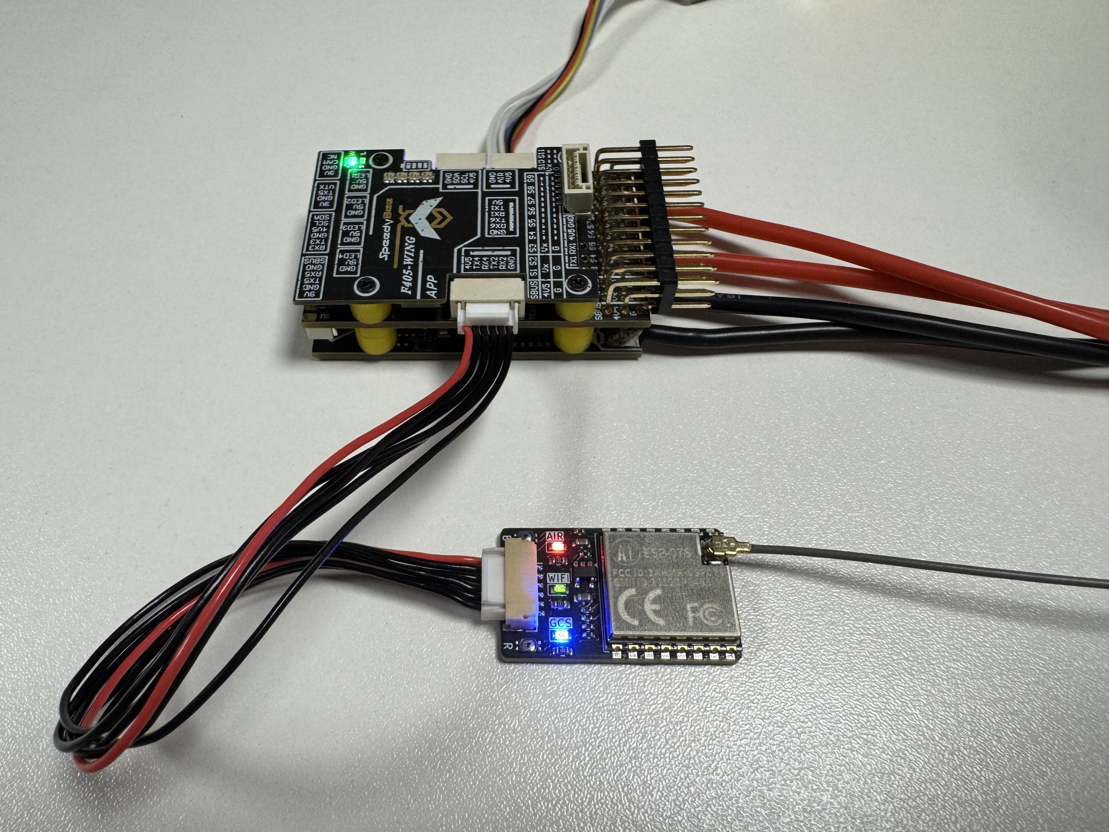
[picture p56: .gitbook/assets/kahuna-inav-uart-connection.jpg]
<figure><figcaption></figcaption></figure>

#### Step 2:

Plug your flight controller into your PC via USB, open INAV Configurator and press Connect.

#### Step 3:

Navigate to the Ports tab on the left of the screen and select MAVLink from the telemetry dropdown of the UART you are using (in this case UART4). Set the baud rate to the baud rate of the Kahuna (Default: 57600). Press Save and Reboot to apply the change.

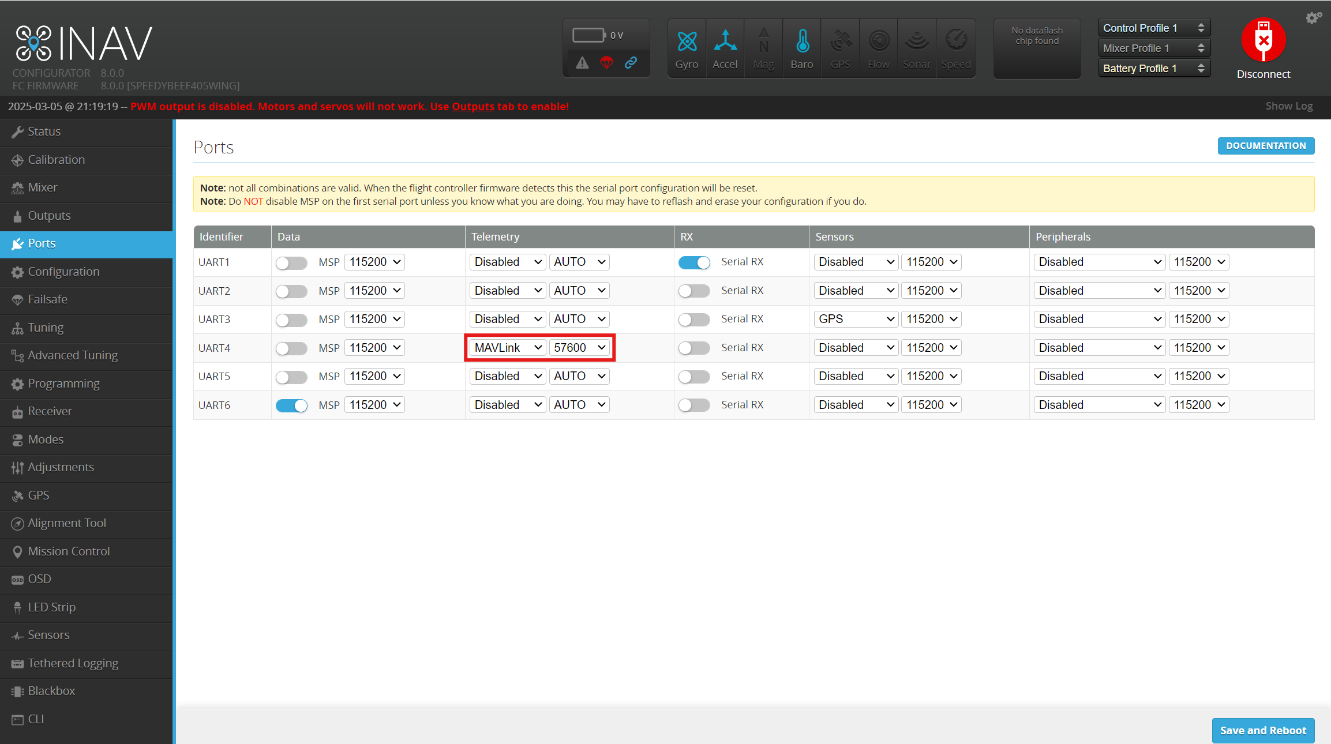
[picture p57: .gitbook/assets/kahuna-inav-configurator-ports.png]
<figure><figcaption></figcaption></figure>

#### Step 4:

Connect your GCS Wi-Fi to the Kahuna \
&#xNAN;_&#x53;SID: BeyondRobotix_\
_Password: beyondrobotix_\
&#xNAN;_(Remember - the password has no capitals)_

#### _Step 5:_

Open Mission Planner, select UDP from the dropdown in the top right corner and press connect. A dialog will open asking you to choose a port, 14550 will already be entered which is the default for the Kahuna. If you have not changed this on the Kahuna setup page you can press OK.

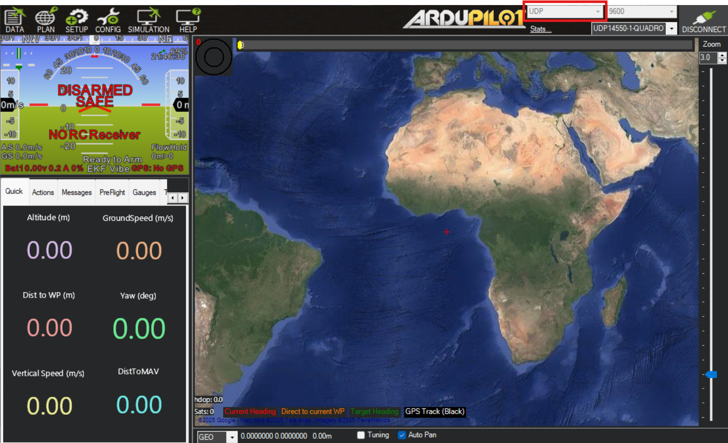
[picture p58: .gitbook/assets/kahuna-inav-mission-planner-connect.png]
<figure><figcaption></figcaption></figure>

You should now see live updates in the artificial horizon when you move your flight controller.

{% hint style="warning" %}
Remember, INAV does not support sending commands over MAVLink, if you attempt to do so the interface will lock up for a few seconds and then show a no response from MAV error message.
{% endhint %}

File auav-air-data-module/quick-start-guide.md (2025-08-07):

# Quick Start Guide

The Beyond Robotix Air Data Module includes the following:

* AUAV Sensor Board
* Micro CAN Node
* Pitot Static Tube
* Silicone tube
* Case

<figure><figcaption></figcaption></figure>

## Assembly

1. Feed the tube through the lid of the case until there is about 1 mm protruding through the lid.&#x20;

<div><figure><figcaption></figcaption></figure> <figure><figcaption></figcaption></figure></div>

2. Insert the AUAV sensor into the tubes and pull the tubes gently until the sensor is flush with the plastic

<div><figure><figcaption><p>Before pulling flush</p></figcaption></figure> <figure><figcaption><p>After pulling flush</p></figcaption></figure> <figure><figcaption><p>Top View</p></figcaption></figure></div>

3. Slide the sensor assembly into the main case and press until you feel a click

<div><figure><figcaption></figcaption></figure> <figure><figcaption></figcaption></figure></div>

4. Fix the pitot static tube to the tubes from the airspeed sensor.&#x20;

<figure><figcaption></figcaption></figure>

{% hint style="success" %}
Ensure the **high** side (H) of the sensor is connected to the **straight** barb on the pitot-static tube (going to the total pressure port) and the **low** side (L) of the sensor to the **diagonal** barb (going to the static ports).
{% endhint %}

5. Connect to one of your CAN ports on your flight controller

<figure><figcaption></figcaption></figure>

5. Set the following parameters, if they are not already set:
   1. CAN\_D1\_PROTOCOL = 1 (DroneCAN)
   2. CAN\_P1\_DRIVER = 1 (First Driver)
   3. ARSPD\_ENABLE = 1 (ENABLE)
   4. ARSPD\_TYPE = 8 (DroneCAN)
6. Save parameters and reboot your autopilot. You should be able to see the airspeed and barometer sensor in the HW ID tab of Mission Planner.

<figure><figcaption><p>Airspeed and barometer show up as UAVCAN</p></figcaption></figure>

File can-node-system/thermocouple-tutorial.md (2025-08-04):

---
description: >-
  A demo of the Arduino DroneCAN library with Beyond Robotix CAN node, using the
  MCP9600 thermocouple reader.
icon: building-columns
---

# Thermocouple Tutorial

## Intro

Do you want to integrate a sensor into Ardupilot or PX4? Arduino DroneCAN and the Beyond Robotix CAN node let you do that very quickly. This tutorial runs through integrating the Adafruit MCP9600 thermocouple sensor, resulting in us being able to send temperature messages over DroneCAN. The big advantage of using the Arduino framework is access to Arduino libraries. Almost always, there are libraries available for the sensor you want to use. This saves development time. The Arduino framework is also simple to work with, and the Platformio + VS code platform allows easy development from small to complicated projects.

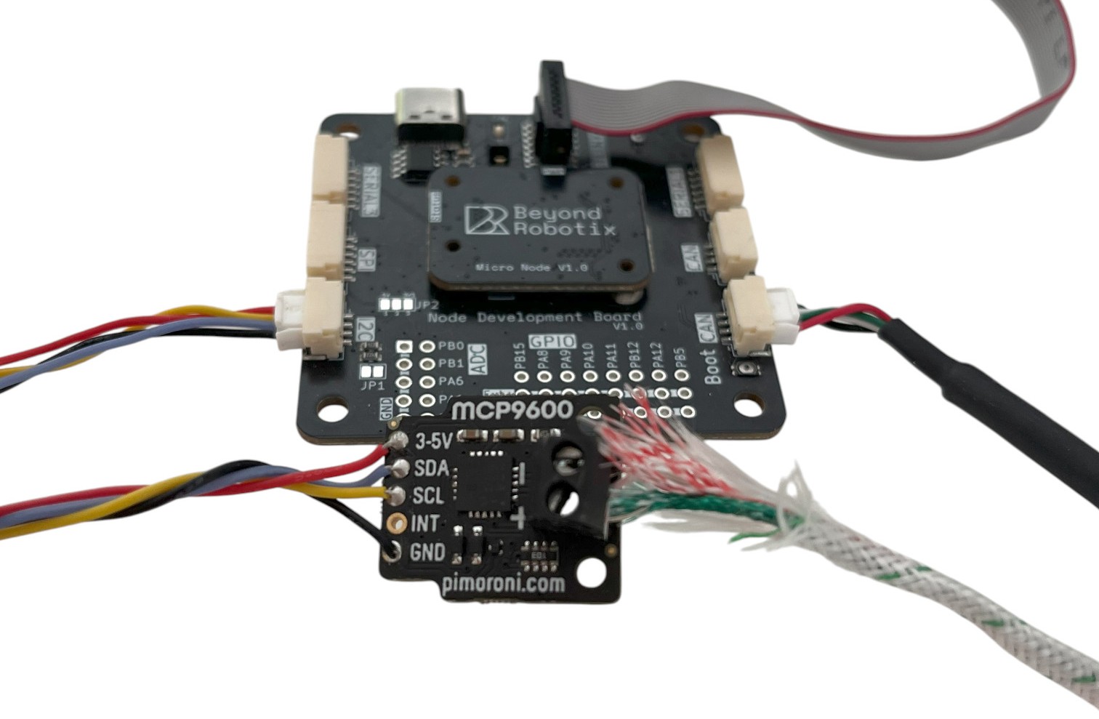
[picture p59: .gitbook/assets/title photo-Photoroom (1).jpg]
<figure><figcaption></figcaption></figure>

Using custom firmware allows lots of options, such as integrating a battery monitor + thermocouple and sending all the information with one device in one message. You could action tasks based on the thermocouple onboard the node, e.g. opening a hatch if the battery is getting too hot.

You could integrate GPS receivers, new airspeed sensors, fuel sensors, gas sensors, ESCs and servo nodes.

## Hardware Requirements

* Beyond Robotix CAN Node Dev Kit - [https://www.beyondrobotix.com/products/micro-can-node-development-bundle](https://www.beyondrobotix.com/products/micro-can-node-development-bundle)
* Flight controller with a CAN bus (Or a CAN 'Sniffer' like the [Zubax Babel](https://shop.zubax.com/products/zubax-babel))
* Windows PC  (Other OS work with minor adjustments)
* [Adafruit MCP9600](https://www.adafruit.com/product/4101) + [Thermocouple](https://www.adafruit.com/product/270)

## Getting started

To start, we should download the latest release of Arduino DroneCAN from:

{% embed url="https://github.com/BeyondRobotix/Arduino-DroneCAN/releases" %}

The code we will run through is in examples/thermocouple-mcp9600 which is here:

{% embed url="https://github.com/BeyondRobotix/Arduino-DroneCAN/tree/master/examples/thermocouple-MCP9600" %}

We’ll need to download a few things to work with the software. We’ve got these setup instructions on our documentation site here:

{% embed url="https://beyond-robotix.gitbook.io/docs/can-node-system/arduino-dronecan" %}

We’ll also need to get our hardware setup. You’ll need a DroneCAN compatible flight controller or sniffer. We’ll use a Cube Orange. Then connect your Beyond Robotix CAN node to the flight controller via a CAN cable. Also, connect your STLINK to the debug port on the CAN node. Lastly, ensure the switch next to the debug port (`SW1`) is set to '1'.

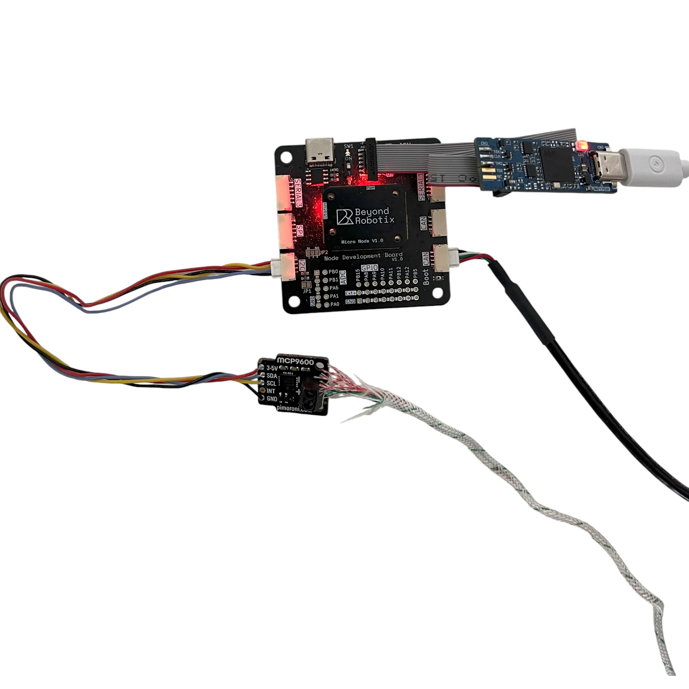
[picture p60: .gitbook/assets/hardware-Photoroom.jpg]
<figure><figcaption></figcaption></figure>

With the repository downloaded and our tools installed, we can build the default example to make sure it’s all working correctly. The default example sends a BatteryInfo message with values from ADC pins PA0 and PA1 as well as MCU temperature.

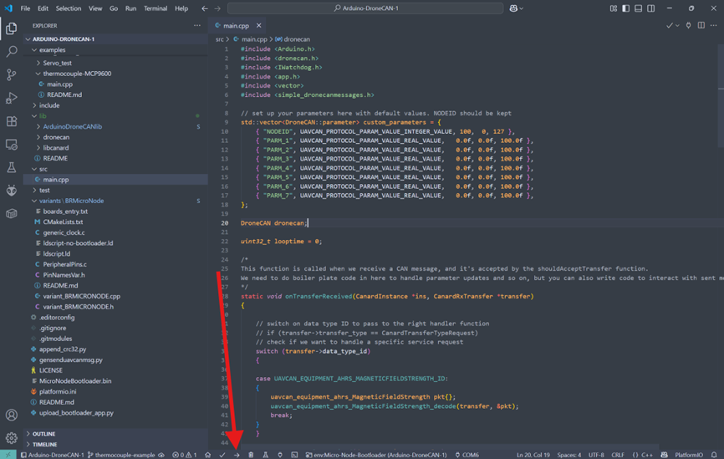
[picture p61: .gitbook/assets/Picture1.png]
<figure><figcaption></figcaption></figure>

You should then see “SUCCESS” shown in the terminal. If you don’t, make sure your STLINK is connected correctly and power is being given to the CAN node via the flight controller.&#x20;

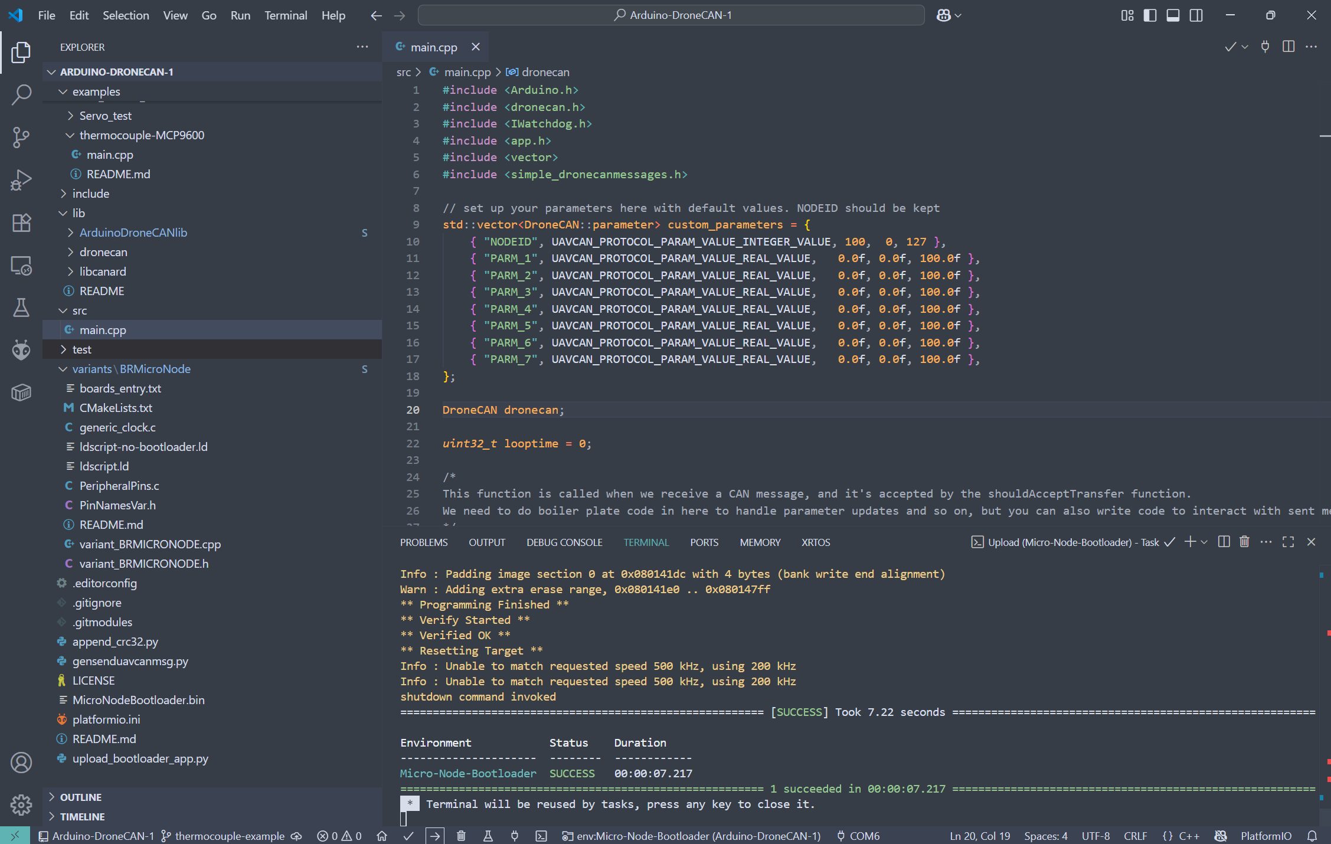
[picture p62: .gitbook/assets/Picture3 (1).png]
<figure><figcaption></figcaption></figure>

We can now see what CAN messages are being sent by the Node. We’ll use DroneCAN GUI tool in this example, however, Mission Planner can also be used for CAN packet inspection.&#x20;

{% embed url="https://dronecan.github.io/GUI_Tool/Overview/" %}

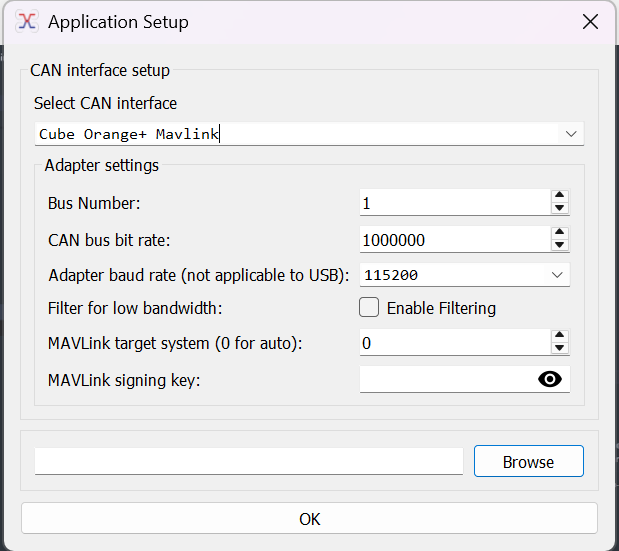
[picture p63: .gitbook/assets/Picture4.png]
<figure><figcaption></figcaption></figure>

Once connected, we’ll see our Node showing in the list, (you may need to set the Local node ID, press the tick in the top left)

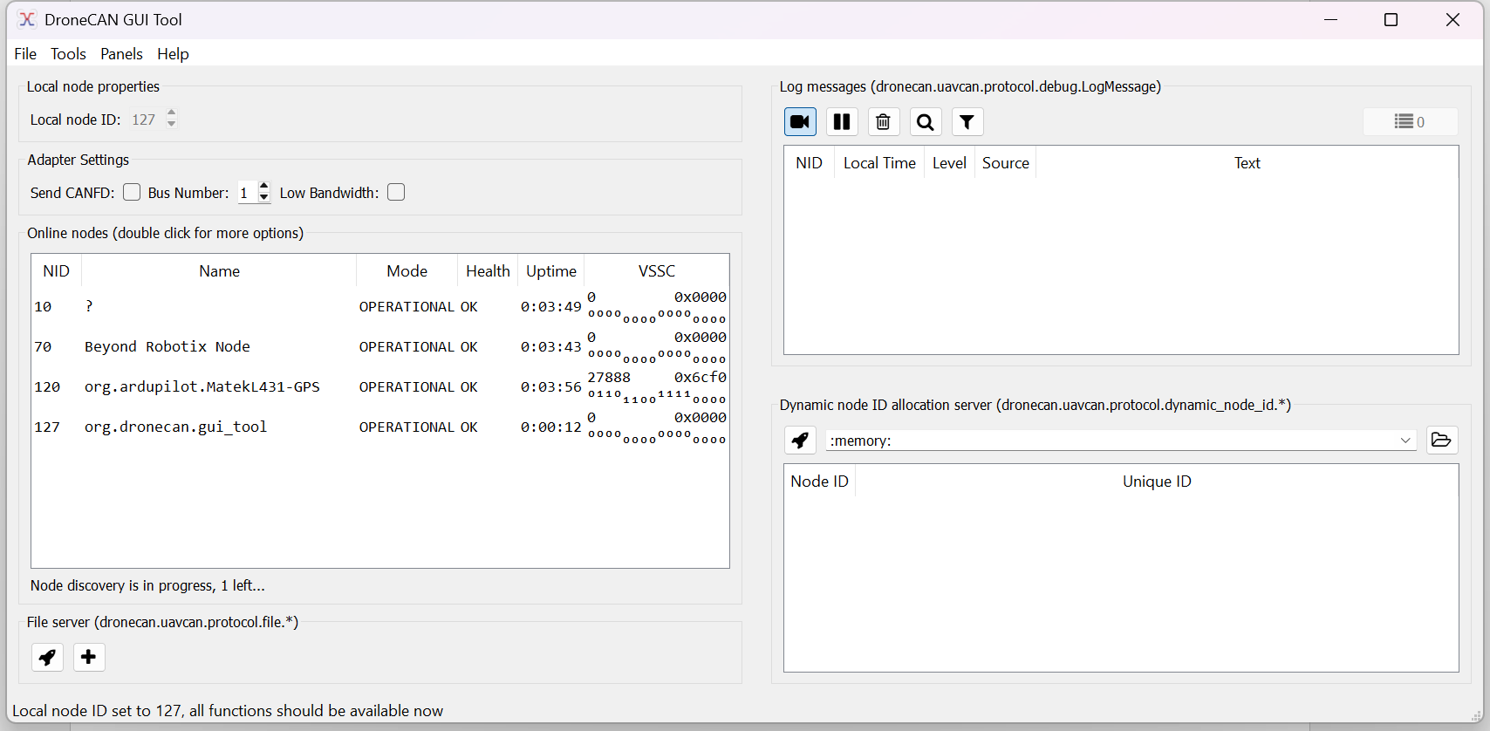
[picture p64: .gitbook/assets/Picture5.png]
<figure><figcaption></figcaption></figure>

We can see the example parameters in Node properties:

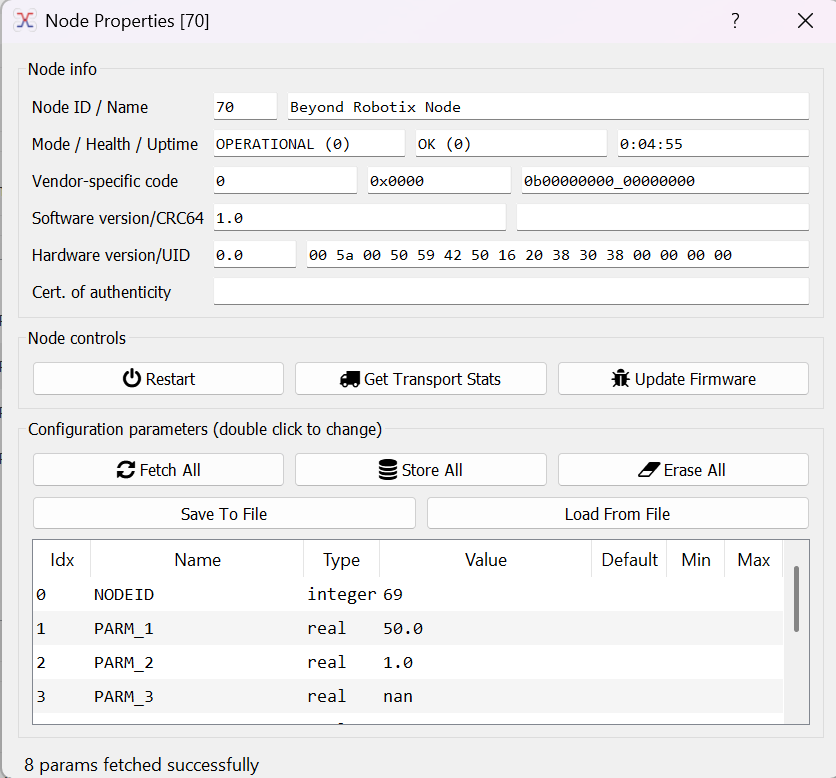
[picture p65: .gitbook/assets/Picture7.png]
<figure><figcaption></figcaption></figure>

And we can also see the battery message being sent (which can be found in Tools > Subscriber)

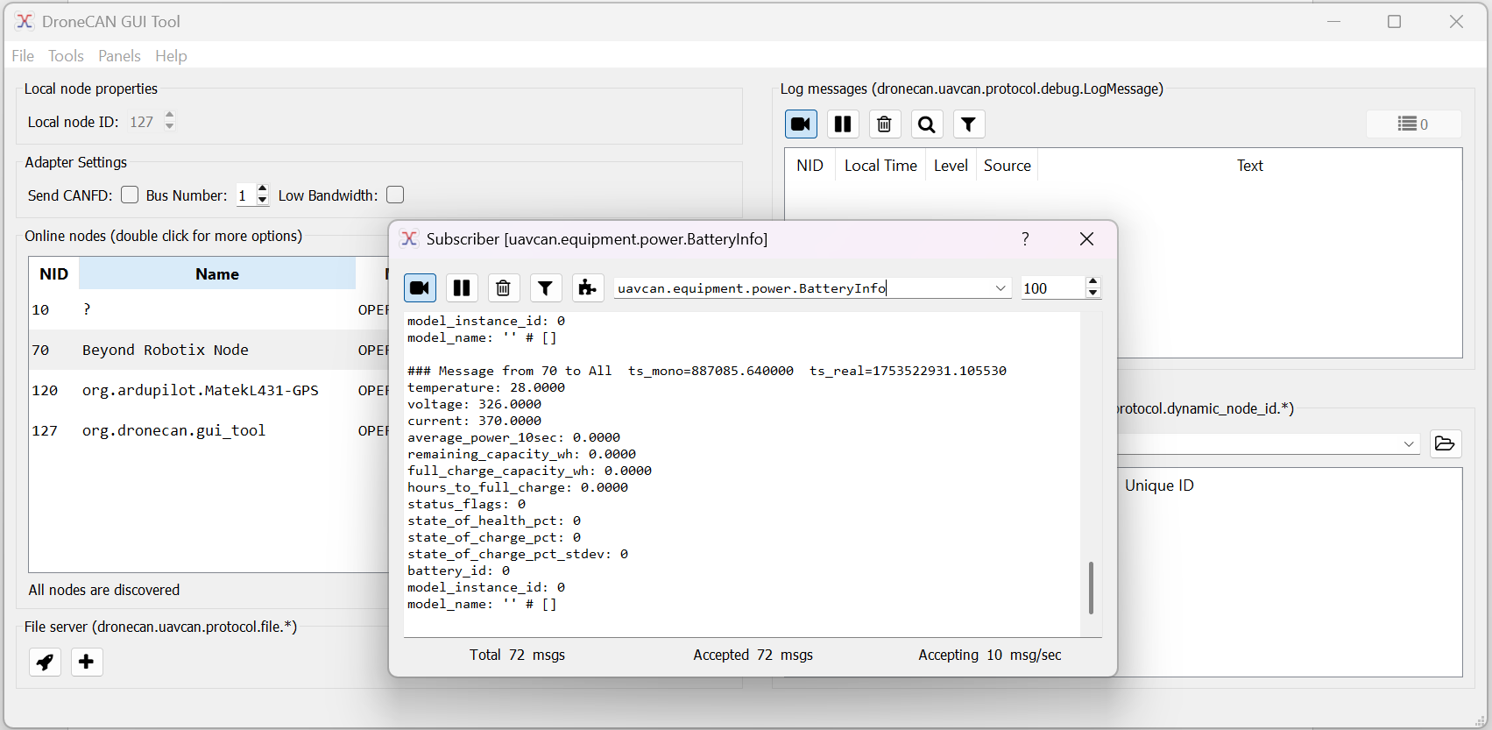
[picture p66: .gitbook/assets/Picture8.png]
<figure><figcaption></figcaption></figure>

We can see the temperature field which responds to the built in MCU temperature sensor. “Voltage” and “current” are showing the raw ADC values from PA1 and PA0 respectively.

## Getting MCP9600 data

We’ve chosen to use the Adafruit library, although there are a few MCP9600 libraries to choose from. Download the latest release, unzip and add it to the “lib” folder in the Arduino DroneCAN repository. Make sure there are no nested folders! The library can also be installed from the platformio library manager. The “BusIO” library is also needed. Platformio may install this for you.

{% embed url="https://github.com/adafruit/Adafruit_MCP9600/releases/tag/2.0.4" %}

{% embed url="https://github.com/adafruit/Adafruit_BusIO/releases/tag/1.17.2" %}

Let's have a look at their example to understand how to use their library.

{% embed url="https://github.com/adafruit/Adafruit_MCP9600/blob/master/examples/mcp9600_test/mcp9600_test.ino" %}

They import the files, set the I2C address and setup the `mcp` object. We had to set the address to 0x66 for the MCP9600 we had.

```cpp
#include <Wire.h>
#include <Adafruit_I2CDevice.h>
#include <Adafruit_I2CRegister.h>
#include "Adafruit_MCP9600.h"

#define I2C_ADDRESS (0x67)

Adafruit_MCP9600 mcp;
```

We then call `.begin` method

```cpp
 /* Initialise the driver with I2C_ADDRESS and the default I2C bus. */
if (! mcp.begin(I2C_ADDRESS)) {
  Serial.println("Sensor not found. Check wiring!");
  while (1);
}
```

Then, they have a bunch of other options but the two we're interested in for the basics:

```cpp
 // set our thermocouple type
 mcp.setThermocoupleType(MCP9600_TYPE_K);
 
 // take a temperature measurement
 mcp.readThermocouple()
```

So, with this information, we can now write our DroneCAN application.

## Writing our app

Now, we go to `main.cpp` in Arduino DroneCAN and add the code from above to our  `setup()` function. We have provided an example for you to follow:

{% embed url="https://github.com/BeyondRobotix/Arduino-DroneCAN/blob/master/examples/thermocouple-MCP9600/main.cpp" %}

Quick aside, in many arduino projects, you might use `delay()`. This can cause problems with Arduino DroneCAN as ot needs to perform functions in the background. So, instead of using `delay()`, setup a statment that only runs once a timer counts to a given time, in this example 1000ms. When not meeting this condition, it always calls "dronecan.cycle()" which processes CAN frames in the background and "IWatchdog.reload()" which ensures our watchdog doesn't reset.

In this example, when we are unable to connect to the MCP9600, we want to keep resending the message every second over CAN and serial to say we have a problem. Instead of using a delay, we use an `if` statement which waits until a time has elapsed while still allowing the background tasks to run.

<mark style="color:$warning;">Bad Code - Don't Use</mark> <mark style="color:$warning;"></mark><mark style="color:$warning;">`delay()`</mark>

<pre class="language-cpp"><code class="lang-cpp"><strong>if (!mcp.begin(I2C_ADDRESS))
</strong>{
    uint32_t deadloop = 0;
    while (1)
    {
        dronecan.debug("MCP9600 not found", 0);
        Serial.println("Sensor not found. Check wiring!");

        dronecan.cycle();
        IWatchdog.reload();
        
        delay(1000);
    }
}

// Set the thermocouple type
mcp.setThermocoupleType(MCP9600_TYPE_K);
</code></pre>

<mark style="color:$success;">Good Code - use</mark> <mark style="color:$success;"></mark><mark style="color:$success;">`if`</mark> <mark style="color:$success;"></mark><mark style="color:$success;">as timer</mark>

```cpp
if (!mcp.begin(I2C_ADDRESS))
{
    uint32_t deadloop = 0;
    while (1)
    {
        const uint32_t now = millis();
        if (now - deadloop > 1000)
        {
            deadloop = millis();
            dronecan.debug("MCP9600 not found", 0);
            Serial.println("Sensor not found. Check wiring!");
        }
        dronecan.cycle();
        IWatchdog.reload();
    }
}

// Set the thermocouple type
mcp.setThermocoupleType(MCP9600_TYPE_K);

```

Another point is we don't use the `void loop()` that arduino uses normally. Instead we have a `while(true){` running at the end of the `void setup()` function.

```cpp
void setup()
{
    # Set up Code
    
    while(true){
        # Looping Code
        
    }  
}  
```

Now, in the example, we've written in some logic which lets you send either a temperature packet or a battery packet depending on some parameters. At the core of it, we send a DroneCAN message like this:

```cpp
uavcan_equipment_device_Temperature pkt{};

pkt.temperature = mcp.readThermocouple();
pkt.device_id = device_id;

sendUavcanMsg(dronecan.canard, pkt);
```

We can see that we read in our thermocouple measurement, and put it into a Temperature packet. You can see the packets availible here:

{% embed url="https://dronecan.github.io/Specification/7._List_of_standard_data_types/" %}

Although there are lots of different types of packets, not all are actually understood by PX4 or Ardupilot, so you'll have to do some research on the appropriate packet to use. If you get stuck you can contact us at **admin@beyondrobotix.com**

We also set the device\_id, which we pull from a parameter in a different part of the loop. This is used by Ardupilot to identify which battery instance to put the temperature into.

We then do our "sendUavcanMsg" which queues our packet.&#x20;

And there we go! If you compile our example, you'll see either battery or temperature packets coming through depending on the parameters set.

We can create fairly complex features easily : - ) If you use the library and/or CAN node in your project, we'd be keen to hear about it! contact us at **admin@beyondrobotix.com**

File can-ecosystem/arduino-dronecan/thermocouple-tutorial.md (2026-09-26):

---
description: >-
  A demo of the Arduino DroneCAN library with Beyond Robotix CAN node, using the
  MCP9600 thermocouple reader.
icon: building-columns
---

# Thermocouple Tutorial

## Intro

Do you want to integrate a sensor into Ardupilot or PX4? Arduino DroneCAN and the Beyond Robotix CAN node let you do that very quickly. This tutorial runs through integrating the Adafruit MCP9600 thermocouple sensor, resulting in us being able to send temperature messages over DroneCAN. The big advantage of using the Arduino framework is access to Arduino libraries. Almost always, there are libraries available for the sensor you want to use. This saves development time. The Arduino framework is also simple to work with, and the Platformio + VS code platform allows easy development from small to complicated projects.

<figure><figcaption></figcaption></figure>

Using custom firmware allows lots of options, such as integrating a battery monitor + thermocouple and sending all the information with one device in one message. You could action tasks based on the thermocouple onboard the node, e.g. opening a hatch if the battery is getting too hot.

You could integrate GPS receivers, new airspeed sensors, fuel sensors, gas sensors, ESCs and servo nodes.

## Hardware Requirements

* Beyond Robotix CAN Node Dev Kit

{% embed url="https://www.beyondrobotix.com/products/micro-can-node-development-bundle" %}

* Flight controller with a CAN bus (Or a CAN 'Sniffer')
* Windows PC is assumed - but other OS’s will apply there might just be some minor adjustments needed
* [Adafruit MCP9600](https://www.adafruit.com/product/4101) + [Thermocouple](https://www.adafruit.com/product/270)

{% hint style="info" %}
You can follow this tutorial on the [CAN Node](../l431-can-node.md) instead - it builds with the same environment and the code is identical. Check its page for where to wire the MCP9600.
{% endhint %}

## Getting started

To start, we should download the latest release of Arduino DroneCAN from:

{% embed url="https://github.com/BeyondRobotix/Arduino-DroneCAN/releases" %}

The code we will run through is in examples/thermocouple-mcp9600 which is here:

{% embed url="https://github.com/BeyondRobotix/Arduino-DroneCAN/tree/master/examples/thermocouple-MCP9600" %}

We’ll need to download a few things to work with the software. We’ve got these setup instructions on our documentation site here:

{% embed url="https://beyond-robotix.gitbook.io/docs/can-ecosystem/arduino-dronecan" %}

We’ll also need to get our hardware setup. You’ll need a DroneCAN compatible flight controller or sniffer. We’ll use a Cube Orange. Then connect your Beyond Robotix CAN node to the flight controller via a CAN cable. Also, connect your STLINK to the debug port on the CAN node. Lastly, ensure the switch next to the debug port (`SW1`) is set to '1'.

<figure><figcaption></figcaption></figure>

With the repository downloaded and our tools installed, we can build the default example to make sure it’s all working correctly. The default example sends a "BatteryInfo" message which we'll see later.

<figure><figcaption></figcaption></figure>

You should then see “SUCCESS” shown in the terminal. If you don’t, make sure your STLINK is connected correctly and power is being given to the CAN node via the flight controller.&#x20;

<figure><figcaption></figcaption></figure>

We can now see what CAN messages are being sent by the Node. We’ll use DroneCAN GUI tool in this example, however, Mission Planner can also be used for CAN packet inspection.&#x20;

{% embed url="https://dronecan.github.io/GUI_Tool/Overview/" %}

<figure><figcaption></figcaption></figure>

Once connected, we’ll see our Node showing in the list, (you may need to set the Local node ID, press the tick in the top left ish)

<figure><figcaption></figcaption></figure>

We can see the example parameters in Node properties:

<figure><figcaption></figcaption></figure>

And we can also see the battery message being sent (which can be found in Tools > Subscriber)

<figure><figcaption></figcaption></figure>

We can see the temperature field which responds to the built in MCU temperature sensor. “Voltage” and “current” are showing the raw ADC values from PA1 and PA0 respectively.

## Getting MCP9600 data

We’ve chosen to use the Adafruit library, although there are a few MCP9600 libraries to choose from. Download the latest release, unzip and add it to the “lib” folder of your project. Make sure there are no nested folders! The library can also be installed from the platformio library manager. The “BusIO” library is also needed. Platformio may install this for you.

{% embed url="https://github.com/adafruit/Adafruit_MCP9600/releases/tag/2.0.4" %}

{% embed url="https://github.com/adafruit/Adafruit_BusIO/releases/tag/1.17.2" %}

Let's have a look at their example...

{% embed url="https://github.com/adafruit/Adafruit_MCP9600/blob/master/examples/mcp9600_test/mcp9600_test.ino" %}

They import the files, set the i2c address and setup the `mcp` object. We had to set the address to 0x66 for the MCP9600 we had.

```cpp
#include <Wire.h>
#include <Adafruit_I2CDevice.h>
#include <Adafruit_I2CRegister.h>
#include "Adafruit_MCP9600.h"

#define I2C_ADDRESS (0x67)

Adafruit_MCP9600 mcp;
```

We then call `.begin` method

```cpp
 /* Initialise the driver with I2C_ADDRESS and the default I2C bus. */
if (! mcp.begin(I2C_ADDRESS)) {
  Serial.println("Sensor not found. Check wiring!");
  while (1);
}
```

then, they have a bunch of other options but the two we're interested in for the basics:

```cpp
 // set our thermocouple type
 mcp.setThermocoupleType(MCP9600_TYPE_K);
 
 // take a temperature measurement
 mcp.readThermocouple()
```

So, with this information, we can now write our DroneCAN application.

## Writing our app

Now, we go to `main.cpp` in Arduino DroneCAN and add the code from above to our  `setup()` function. We have provided an example for you to follow:

{% embed url="https://github.com/BeyondRobotix/Arduino-DroneCAN/blob/master/examples/thermocouple-MCP9600/main.cpp" %}

In many arduino projects, you might use `delay()`. This can cause problems with Arduino DroneCAN as to needs to perform functions in the background. So, instead of using `delay()`, setup a statement that only runs once a timer counts to a given time, in this example 1000ms. When not meeting this condition, it always calls "dronecan.cycle()" which processes CAN frames in the background and "IWatchdog.reload()" which ensures our watchdog doesn't reset.

In this example, when we are unable to connect to the MCP9600, we want to keep resending the message every second over CAN and serial to say we have a problem. Instead of using a delay, we use an `if` statement which waits until a time has elapsed while still allowing the background tasks to run.

```cpp
if (!mcp.begin(I2C_ADDRESS))
{
    // used to keep track of the time the last debug statement was run 
    uint32_t deadloop = 0;
    
    while (1)
    {
        // see what our current time is
        const uint32_t now = millis();
        
        // check if enough time has passed to activate our debug statements
        if (now - deadloop > 1000)
        {
            // refresh the timer, so the next one will trigger in 1000ms
            deadloop = millis();
            
            dronecan.debug("MCP9600 not found", 0);
            Serial.println("Sensor not found. Check wiring!");
        }
        
        // cycle through recieve and transmit CAN messages
        dronecan.cycle();
        // reset Watchdog to make sure the watchdog doesn't reset us
        IWatchdog.reload();
    }
}
```

The `void loop()` that Arduino uses normally works as you'd expect, so the code is laid out in the usual way. Sensor setup goes in `void setup()`, and the repeating work goes in `void loop()` with `dronecan.cycle()` and `IWatchdog.reload()` at the bottom of it.

```cpp
void setup()
{
    // Set up Code
}

void loop()
{
    // Looping Code

    dronecan.cycle();
    IWatchdog.reload();
}
```

{% hint style="info" %}
Older versions of this library couldn't use `loop()` and needed a `while(true)` at the end of `setup()` instead. If you're following an older tutorial or example that does this, it still works - there's no need to rewrite it.
{% endhint %}

Now, in the example, we've written in some logic which lets you send either a temperature packet or a battery packet depending on some parameters. At the core of it, we send a DroneCAN message like this:

```cpp
uavcan_equipment_device_Temperature pkt{};

pkt.temperature = mcp.readThermocouple();
pkt.device_id = device_id;

sendUavcanMsg(dronecan.canard, pkt);
```

We can see that we read in our thermocouple measurement, and put it into a Temperature packet. You can see the packets available here:

{% embed url="https://dronecan.github.io/Specification/7._List_of_standard_data_types/" %}

Although there are lots of different types of packets, not all are actually understood by PX4 or Ardupilot, so you'll have to do some research on the appropriate packet to use. If you get stuck you can contact us at **admin@beyondrobotix.com**

We also set the device\_id, which we pull from a parameter in a different part of the loop. This is used by Ardupilot to identify which battery instance to put the temperature into.

We then do our "sendUavcanMsg" which queues our packet.&#x20;

And there we go! If you compile our example, you'll see either battery or temperature packets coming through depending on the parameters set.

We can create fairly complex features easily : - ) If you use the library and/or CAN node in your project, we'd be keen to hear about it! contact us at **admin@beyondrobotix.com**

## Breakpoint debugging

We can debug our programs easily with an STLINK. This is included in the Micro CAN node dev kit. Breakpoint debugging is very useful, being able to see the value of variables in real time as the program runs.&#x20;

This works as standard in PlatformIO debugging, with your normal build environment. It previously needed a special flash without the bootloader, but this is no longer an issue.

1. You can now use the standard -app environment for your board
2. Set a breakpoint where you're interested in seeing the program state
3. Change to the Debug VS code tab
4. Start the debug session

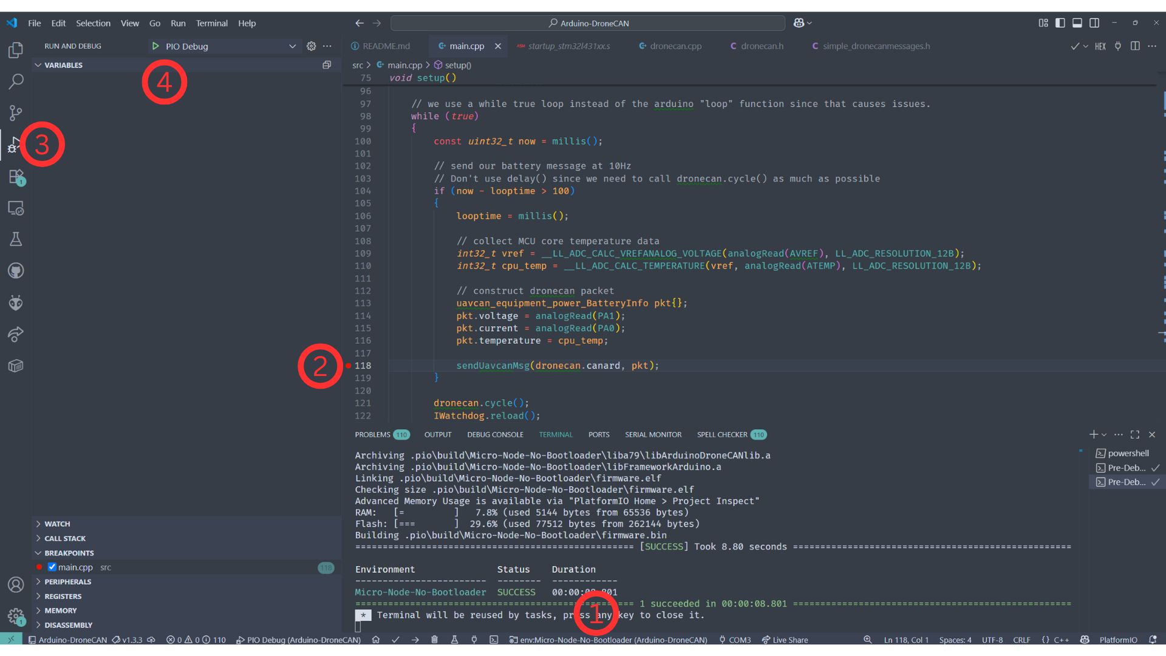
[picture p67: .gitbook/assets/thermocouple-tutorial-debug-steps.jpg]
<figure><figcaption></figcaption></figure>

After the program rebuilds, and starts running, the program now stops at where we set our breakpoint. We can see all the in scope variables on the left, and you can even hover over variables in the code to see their value.&#x20;

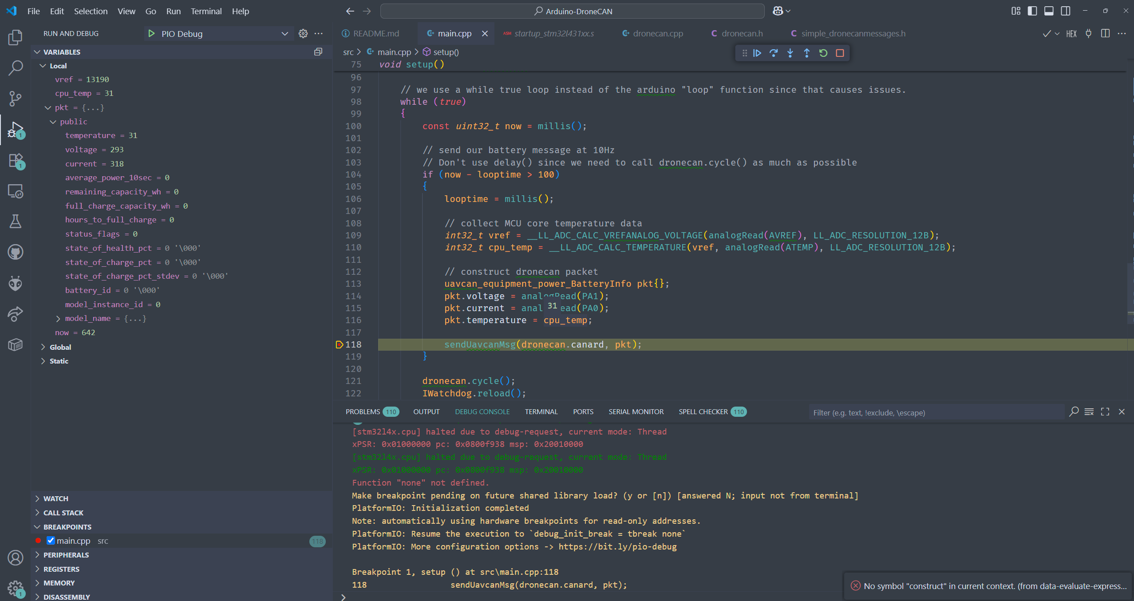
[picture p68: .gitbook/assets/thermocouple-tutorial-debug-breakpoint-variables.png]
<figure><figcaption></figcaption></figure>

The bootloader stays on the node throughout, so you can keep updating firmware over CAN while you're developing.

## Folder structure

The project itself is deliberately small. The library, the board definitions and the bootloader binary all live in separate repositories now, and PlatformIO downloads them for you on the first build.

* .pio -> transient, contains all the build files. We can grab our .bin file from here if we want to distribute the program. The downloaded library ends up in ".pio/libdeps"
* .vscode -> vscode config files
* assets -> Just used for our repository for logos etc
* examples -> contains all the code examples that will hopefully help you on how to use the library. Each example contents can be copied to "src/main.cpp" to run them. Bear in mind you may need additional library configuration to run them. This should be in the README of each example folder.
* lib -> any arduino libraries you want to manually download and unzip go here. Create it if it isn't there
* src/main.cpp -> Our core program!
* platformio.ini -> specifies how platformio interacts with the project, including which versions of the library and board definitions to fetch

The things that used to live in this project and have moved out:

* the core "Arduino DroneCAN lib" files, the DroneCAN message headers and libcanard are now in [libArduinoDroneCAN](https://github.com/BeyondRobotix/libArduinoDroneCAN). You can still modify these to extend the library - we're open to PRs : )
* the board definitions, pinmaps, linker scripts and the bootloader binary are now in [br\_platformio\_hwdef](https://github.com/BeyondRobotix/br_platformio_hwdef). This is why there's no "boards", "variants" or "MicroNodeBootloader.bin" in the project any more, and why one upload flashes both the bootloader and your app.

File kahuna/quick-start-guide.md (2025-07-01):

---
description: Set up your Kahuna in 3 easy steps
icon: diagram-project
---

# Quick Start Guide

**Step 1:**

Connect the Kahuna to your autopilot

**Step 2:**

Power on your GCS and your UAV

**Step 3:**

Connect your GCS Wi-Fi to the Kahuna \
&#xNAN;_&#x53;SID: BeyondRobotix_\
_Password: beyondrobotix_\
&#xNAN;_(Remember - the password has no capitals)_

Misson Planner or QGroundControl will connect to your UAV automatically!

***

If that didn't work, try setting these parameters in your autopilot.

If using **PX4**, set the following parameters:\
SER\_TEL1\_BAUD = 57600 (57600 8N1)

If using **ArduPilot**, set the following parameter\
SERIAL1\_BAUD = 57 (57600) \
SERIAL1\_PROTOCOL = 2 (MAVLink2)

{% hint style="info" %}
This assumes you are plugging the Kahuna into Telem1. If you are plugging it into Telem 2, use SERIAL2\_BAUD and SERIAL2\_PROTOCOL for Ardupilot and SER\_TEL2\_BAUD for PX4
{% endhint %}

{% hint style="warning" %}
Make sure to reboot your autopilot after changing parameters.
{% endhint %}

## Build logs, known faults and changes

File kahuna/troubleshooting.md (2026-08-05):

---
description: Common issues and how to fix them
icon: circle-exclamation
---

# Troubleshooting

#### Air (red) LED blinking when Kahuna is plugged into the autopilot?

The Kahuna is not receiving a heartbeat from your autopilot. Ensure that the baud rate of the serial port which the Kahuna is connected to matches the baud rate of the Kahuna, by default the Kahuna baud rate is 57600.

#### Connected to Wi-Fi but not to ground control station software (solid green LED, blinking blue LED)?

This is most likely caused by your firewall. You need to ensure that your GCS software is allowed to receive incoming connections on port 14550. This can be done by allowing your GCS software through the firewall.

1. Search for "Firewall & network protection" in the start menu search bar
2. Select "Allow an app through the firewall" and find your GCS software in the list
3. Click on "Change settings" and then make sure the box for "Private" is checked
4. If your GCS software is not in the list, click on "Allow another app..." and then in the menu that opens click on "Browse..." and then find and select the .exe of your GCS software. For Mission Planner this is usually `C:\Program Files (x86)\Mission Planner\MissionPlanner.exe`. For QGroundControl this is usually `C:\Program Files\QGroundControl\QGroundControl.exe`.

Now that your GCS is allowed to communicate on private networks, you need to set up the Kahuna Wi-Fi network as a private network.

1. Select Start , then type "settings". Select Settings > Network & internet > Wi-Fi.
2. On the Wi-Fi settings screen, select Manage known networks, and select the Kahuna Wi-Fi network you're connected to.
3. On the Wi-Fi network screen, under Network profile type, select Private network

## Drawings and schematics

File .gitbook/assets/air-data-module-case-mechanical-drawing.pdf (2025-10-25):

32 30.5

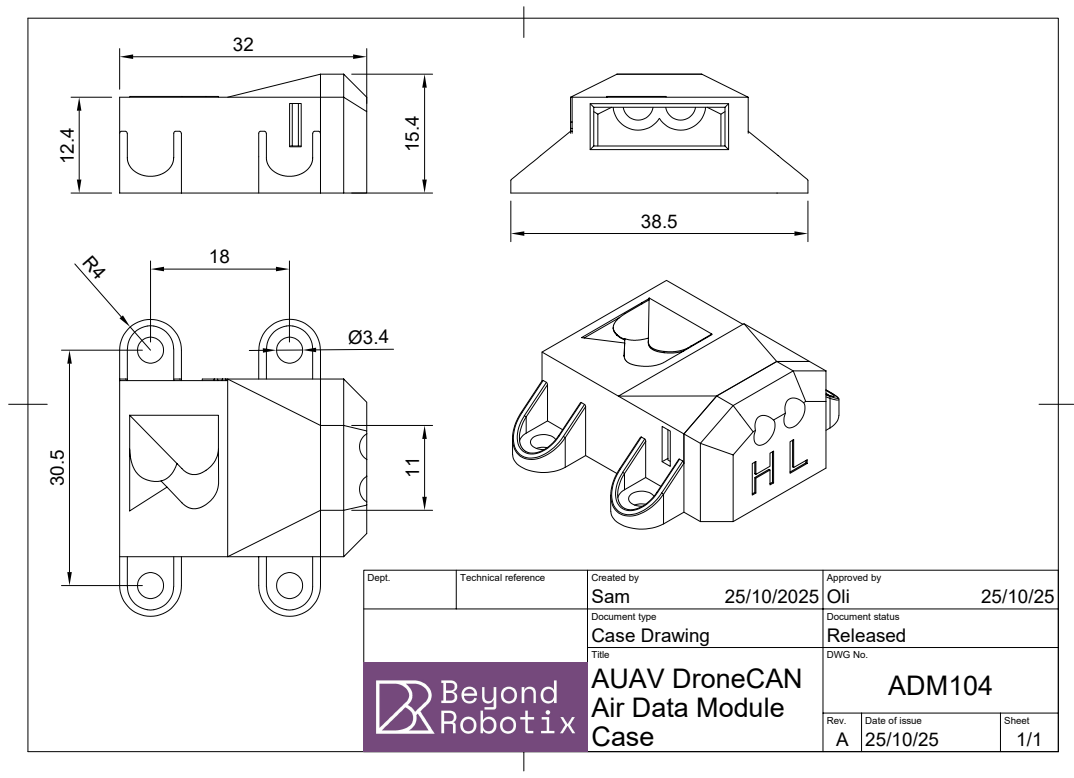
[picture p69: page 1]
Dept.; Technical reference; Created by; Approved by; Sam; Oli

Document type Case Drawing | Document status Released

Title AUAV DroneCAN Air Data Module Case | DWG No. ADM104

Rev. A | Date of issue 25/10/25 | Sheet 1/1

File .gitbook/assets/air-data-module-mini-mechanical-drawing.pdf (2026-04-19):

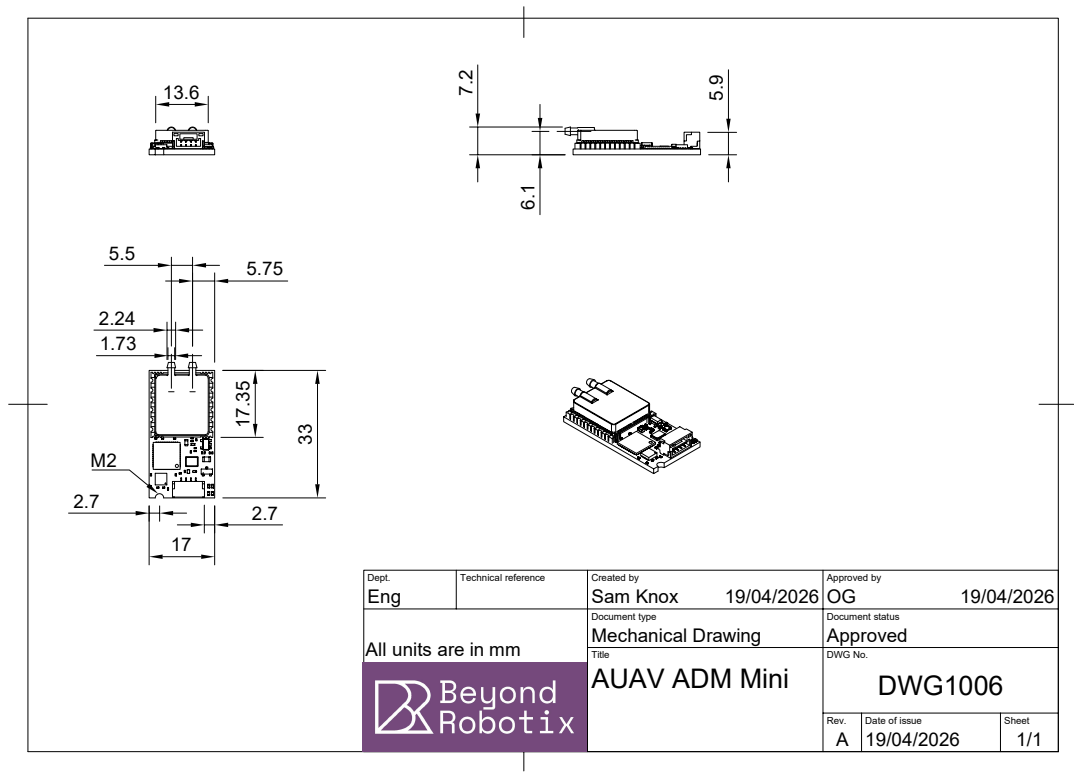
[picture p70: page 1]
Dept.; Technical reference; Created by; Approved by; Document type; Document status; Mechanical Drawing; Approved; Eng; Sam Knox

All units are in mm

Title AUAV ADM Mini | DWG No. DWG1006

Rev. A 19/04/2026 | Date of issue | Sheet 1/1

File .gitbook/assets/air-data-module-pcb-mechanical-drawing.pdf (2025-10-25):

Sam | Oli ⁹.6 | 10.4 9

20

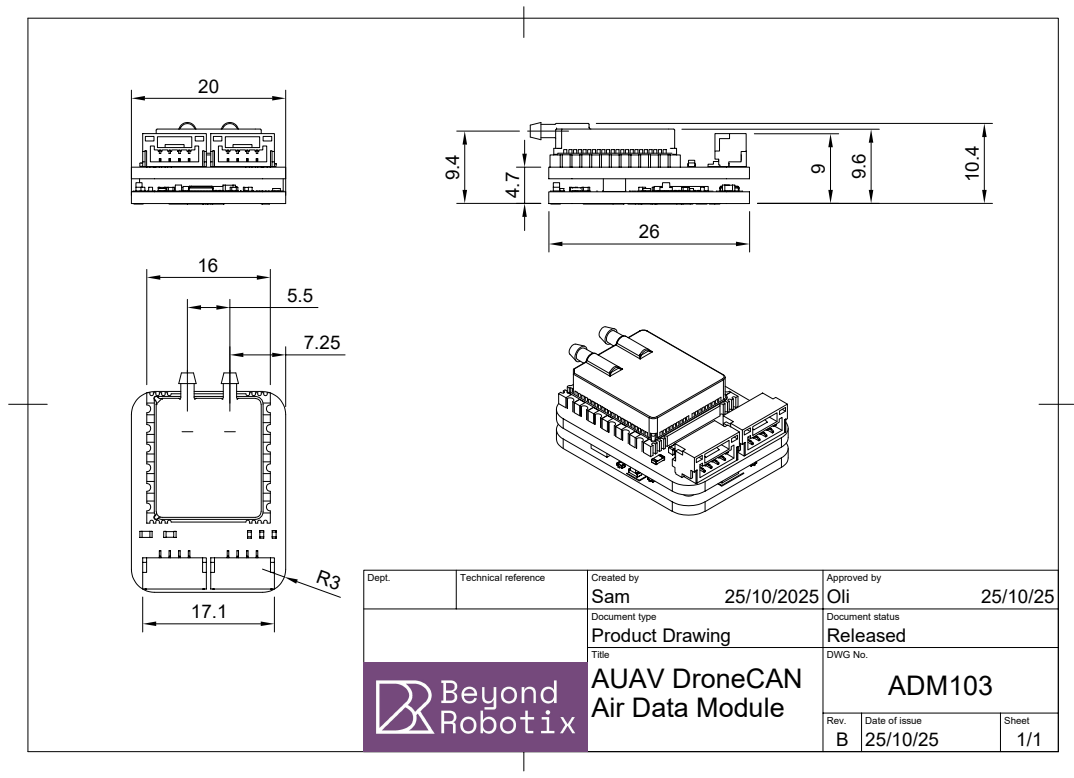
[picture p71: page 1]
Dept.; Technical reference; Created by; Approved by; Document type; Document status; Product Drawing; Released

Title AUAV DroneCAN Air Data Module | DWG No. ADM103

Rev. B 25/10/25 | Date of issue | Sheet 1/1

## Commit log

2025-07-01 GITBOOK-52: No subject
    [BaseV2_2.SLDPRT, BaseV2_2.STL, KahunaV1.2 (1).step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]
2025-08-07 GITBOOK-69: No subject
    [Airspeed Base.stl, Airspeed Lid.stl]
2025-08-17 GITBOOK-74: No subject
    [V1.1 Beyond Robotix CAN Dev board.step]
2025-10-23 GITBOOK-75: No subject
    [Airspeed Base (1).stl, Airspeed Lid (1).stl]
2025-10-23 GITBOOK-77: No subject
    [BR AUAV ADM Base.3mf, BR AUAV ADM Lid.3mf]
2025-12-26 GITBOOK-83: No subject
    [BR ADM AUAV Base.step, BR ADM AUAV Lid.step, BR AUAV ADM Base.step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]
2026-01-30 GITBOOK-84: No subject
    [KahunaV1.2 (2).step]
2026-03-22 GITBOOK-85: No subject
    [Mag Node RM3100.step]
2026-04-19 GITBOOK-89: No subject
    [AUAV ADM.step]
2026-08-04 Update Arduino DroneCAN docs for libArduinoDroneCAN 2.x
    The Arduino DroneCAN pages still described the 1.3.x single-repository
    layout and API. Bring them in line with the current code.
    Corrections:
    - No submodules. The library and board definitions are separate repos
    fetched by PlatformIO from pinned tags in platformio.ini.
    - Environments are Micro-Node-App / Core-Node-App / Micro-Node-Plus-App,
    not Micro-Node-Bootloader. The -App suffix is what triggers the
    two-stage bootloader+app upload.
    - Micro-Node-No-Bootloader is no longer shipped; document how to add one
    for breakpoint debugging.
    - loop() works now. The while(true)-in-setup() workaround is gone.
    - init() callbacks are option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
2026-08-04 Cover the L431 Plain CAN node in the Arduino DroneCAN docs
    The Plain node has its own hardware page and is sold for Arduino
    DroneCAN development, but the Arduino DroneCAN pages didn't mention it,
    so there was nothing telling you which environment to build for it.
    - Added it to the supported hardware table. It's the same L431 as the
    Micro Node, so it uses Micro-Node-App with nothing to change.
    - Mapped Serial / Serial1 / Serial3 onto its physical connectors, since
    it breaks its interfaces out to fixed connectors rather than through a
    board-to-board connector.
    - Noted that it has no SW1 debug switch, in both the install steps and
    the tutorial's hardware setup.
    - Noted in the thermocou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
2026-08-04 Add the Plain CAN node to the CAN Ecosystem landing page
    It was the only hardware page in the section with no entry on the
    landing page, so the product page was the only way to find it.
2026-08-04 Show the H7 dual CAN interfaces in the supported hardware table
    Adds a CAN ports column, and a line making clear the two ports on the
    H7 boards are independent interfaces - separate node IDs and parameter
    values, able to sit on two separate buses - rather than one bus brought
    out on two connectors.
2026-08-04 Don't restate board interface details in the Arduino DroneCAN pages
    Connectors, pinouts and per-board wiring belong on each board's own
    page, not repeated here - the Micro Node isn't documented that way
    either. Drops the Plain node serial mapping table, the ADC/PWM note,
    and the SW1 / STLINKV3 asides, leaving just which environment to build
    and a pointer to the board pages.
2026-08-10 Rewrite and reorganize the L431 CAN node page, dropping "Plain" naming
    Renames l431-plain-can-node.md to l431-can-node.md and restructures it
    into clear Overview/Specifications/Firmware/Mechanical/Pinout sections.
    Clarifies that the board is primarily built for the Arduino DroneCAN
    library, with AP_Periph as the default shipped firmware, and folds in
    the AP_Periph hwdef details, parameter reference, and board-specific
    firmware files. Updates all "Plain"/"L431 CAN Node" references across
    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
2026-08-10 GITBOOK-101: Format ADC pin mapping as table
2026-08-12 Add a Micro Node Plus hardware page (#3)
    * Add a Micro Node Plus hardware page
    [Micro-Node-Plus.step]
2026-09-02 Updated Micro Node Plus to CAN Node Plus.
    [CAN-Node-Plus.step]
2026-09-08 Update heated pitot docs from firmware repo (#7)
    Sync heated-pitot/parameters.md and telemetry.md with the current
    HeatedPitot firmware docs, verified against src/main.cpp and src/heater.h.
    Parameters:
    - Remove KP, KI, KD, CHANGE_LIMIT, RAMP_S and MIN_POWER. The gains and the
    rate-of-change limit are now fixed firmware constants; RAMP_S and
    MIN_POWER were already ignored by the control path.
    - Add TELEM_EN, R_HEATER and SELFTEST with full descriptions.
    Telemetry:
    - Extend the state enum from 0-6 to 0-9: STANDBY (5) and STANDARD (6) are
    no longer entered, and UNPOWERED (7), SELFTEST (8) and CONTROL (9) are
    appended. Normal operation is now CONTROL (9).
    - Note that current is inferre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
2026-09-08 Restore README to pre-rework state (#8)
    * Restore README to pre-rework state
    Reverts the three GITBOOK commits of 2026-09-03 (c3bd04d, a4abf3b,
    af84037) that replaced the landing page, returning README.md to
    905b8a6 -- the "Welcome!" page that stood from 2025-07-01.
    This drops the Products, CAN development and Get started sections and
    returns to the V2 logo.
    * Use the V3 logo on the restored README
    Keeps the restored "Welcome!" page but points the figure at
    LogoPurpleBack V3.png with width="375", matching how V3 was used before
    the landing page was replaced.
    ---------
    Co-author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
2026-09-16 hp progress
    [Beyond Robotix Heated Pitot Space Model.step, Heated Pitot Control Module.step]
2026-09-16 Revert "hp progress"
    This reverts commit 3e6d8c309c79df6b995dd176d0bc172146169efa.
    [Beyond Robotix Heated Pitot Space Model.step, Heated Pitot Control Module.step]
2026-09-17 Heated Pitot: mechanical, electrical, and images (#9)
    [Beyond Robotix Heated Pitot Space Model.step, Heated Pitot Control Module.step]
2026-09-21 Rework homepage as a described table of contents
    Replaces the image-heavy landing page with a plain text ToC: one
    section per product/category, a short human description, and a
    bulleted list of its docs pages with readable link text (no raw
    filenames or .md shown).
2026-09-26 Core Autopilot docs (#6)
    [Airspeed Base (1).stl, Airspeed Base.stl, Airspeed Lid (1).stl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]
